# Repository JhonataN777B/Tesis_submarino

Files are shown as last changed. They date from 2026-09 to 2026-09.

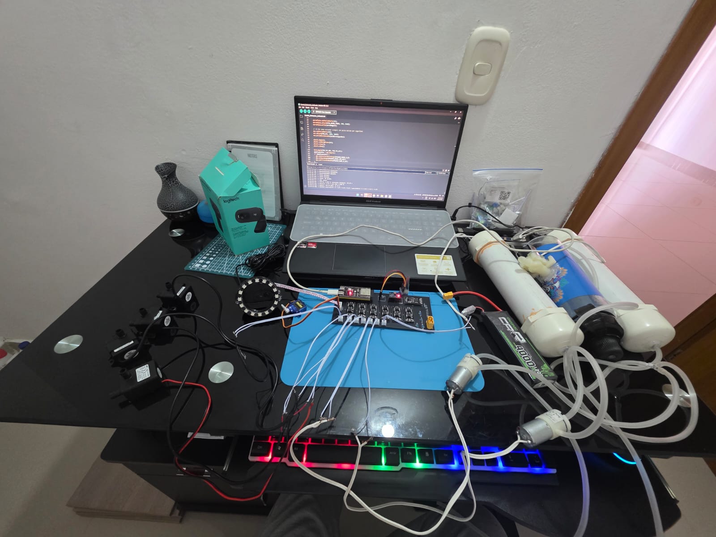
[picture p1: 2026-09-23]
docs/evidencia/pcb/Montaje.jpeg

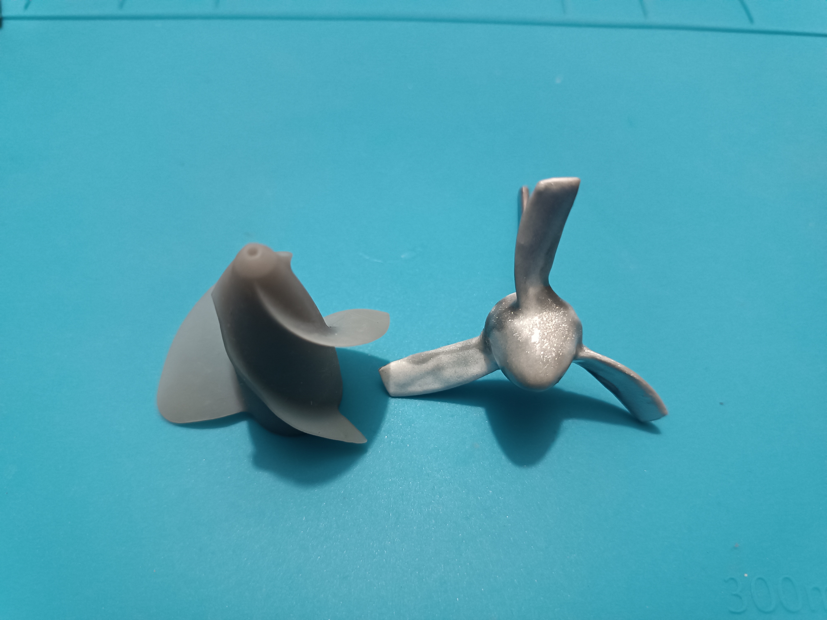
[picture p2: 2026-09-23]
docs/evidencia/primera_version_submarino/231.jpg

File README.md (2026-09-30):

# ROV / Submarine thesis

Repository for the low-cost remotely operated vehicle (ROV): ESP32-S3 firmware, surface-control interface, hardware exports, telemetry examples, and validation evidence.

## Repository layout

- firmware/integrated: current ESP32-S3 integrated firmware.
- firmware/tests: independent Arduino sketches for sensor and actuator checks.
- interface/solo_control.py: current joystick, serial, camera HUD, telemetry, logging, and recording application.
- interface/prueba_control_mando.py: independent PG-9076/Pygame axis and button diagnostic.
- hardware: PCB files and STL models used for the printed assembly.
- data: a lightweight, illustrative telemetry sample. Runtime logs are not committed.
- docs/evidencia: PCB, design, and selected operational evidence videos.

## Current integration

The firmware streams telemetry at 10 Hz over 115200-baud serial and accepts text commands on the same port. It reads the ACS712, battery divider, MS5837 pressure sensor, and BNO055/SEN0374 orientation sensor when available. Missing sensor values are printed as --. The Python interface accepts current 24-field rows and legacy 20-field rows.

The BNO055 is configured for NDOF fusion. The Python HUD shows heading (yaw), pitch, and roll, and logs telemetry; the current software does not implement automatic attitude or depth stabilization.

The Python controller defaults to COM3 and camera index 1. Adjust those settings in interface/solo_control.py for the computer in use. Close Arduino Serial Monitor before starting the Python app because both need the same COM port.

## Setup

1. Open firmware/integrated/Control_Submarino_Unificado.ino in Arduino IDE.
2. Install ESP32Servo, Adafruit NeoPixel, a compatible MS5837 library, and DFRobot_BNO055.
3. Install Python dependencies from interface/requirements.txt.
4. Set the correct serial port and camera index in interface/solo_control.py.
5. Review docs/protocolo_serial.md and docs/pruebas.md before an integrated test.

Keep the vehicle restrained and verify stop/neutral before testing propulsion.

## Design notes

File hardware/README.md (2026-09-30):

# Hardware

## PCB

- pcb/BOM_Tesis_2026-08-29.csv: lista de materiales exportada del diseno.
- pcb/Gerber_Tesis_PCB_Tesis_2026-08-29.zip: paquete Gerber para fabricacion.
- pin_map.md: asignacion de GPIO del ESP32-S3.

## Modelos STL usados para impresion

- Pieza_frontal.stl y Pieza_trasera.stl: piezas frontal y trasera.
- soporte_garra.stl: soporte de la pinza.
- soporte_motor.stl: soporte del motor.
- soporte_1.stl, soporte_2.stl y soporte_3.stl: soportes complementarios.

Estos son exportes STL para fabricacion. Los archivos CAD editables, el proyecto de Inventor/Blender y simulaciones se conservan en las carpetas de trabajo originales.

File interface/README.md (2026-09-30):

# Control de superficie

## Aplicacion integrada

solo_control.py es la aplicacion activa para el mando Bluetooth, ESP32, HUD de camara, visualizacion de telemetria, graficas, logs y grabacion del HUD.

Instale las dependencias con:

    pip install -r requirements.txt

Ajuste PUERTO_COM y CAMARA dentro de solo_control.py. El programa usa 115200 baudios y comparte el puerto serie con los comandos del ESP32. Cierre el Monitor Serial de Arduino antes de ejecutar Python.

El firmware emite telemetria a 10 Hz. El panel muestra la lectura de sensores; los valores ausentes aparecen como --. Los logs CSV de cada sesion y su espejo de respaldo se escriben en interface/Logs_Submarino cuando el programa se ejecuta desde esta carpeta. Las grabaciones iniciadas desde el mando se guardan en Grabaciones_HUD.

## Mando PG-9076

Indices confirmados con Pygame:

| Control | Funcion |
| --- | --- |
| Palanca izquierda vertical | Control del ESC (1000-2000 us; neutro 1500 us) |
| Palanca derecha horizontal | Orden de giro derecha/izquierda |
| Palanca derecha vertical | Orden de roll derecha/izquierda |
| A, boton 0 | Solicita reinicio seguro del ESP32 |
| B, boton 1 | Alterna abrir/cerrar pinza |
| X, boton 3 | Alterna bomba de aire 1 |
| Y, boton 4 | Alterna bomba de aire 2 |
| Boton 7 | Alterna electrovalvula |
| Boton 10 | Inicia/detiene grabacion del HUD |
| Start, boton 11 | Alterna LISTO/OPERANDO |

Start deja el vehiculo en LISTO al detener y exige centrar las palancas antes de habilitar movimiento al volver a OPERANDO. El boton A solicita el reinicio seguro del ESP32.

La tecla G cambia entre HUD y graficas; R alterna la grabacion y Q cierra la ventana. El boton 10 del mando tambien alterna la grabacion.

## Diagnostico independiente del mando

prueba_control_mando.py muestra ejes, botones y cruceta sin controlar el ROV. Uselo para comprobar un mando o volver a confirmar su mapeo antes de operar.

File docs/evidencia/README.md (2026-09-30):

# Evidencia del proyecto

## Primera version construida

Las fotos de primera_version_submarino documentan la primera unidad construida y no representan por si solas la configuracion de version 2.

## Version 2 y PCB

- version_2_submarino contiene renders del diseno de la segunda version.
- pcb contiene DATOS.jpeg y Montaje.jpeg de la PCB.

## Pruebas de operacion (30-09-2026)

- [Prueba de funcionamiento del aro LED](operacion/aro_led_operativo_2026-09-30.mp4).
- [Telemetria en tiempo real](operacion/telemetria_tiempo_real_2026-09-30.mp4).

## FEA y archivos tecnicos

Las pruebas FEA e imagenes se conservan en el documento compartido por el usuario: [Abrir documento FEA](https://1drv.ms/w/c/5849b21efb36e423/IQC6wTvbUKNUTo-QrPtmvVhxAYxSXWxDTwB7AuLJp3VFQAA?e=XMopzp).

Los modelos STL de fabricacion estan en ../../hardware. Los modelos CAD editables, Blender y simulaciones permanecen en las carpetas de trabajo del proyecto.

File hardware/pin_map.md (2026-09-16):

# Mapa de pines — ESP32-S3

Fuente: `firmware/integrated/Control_Submarino_Unificado.ino`. Validar en el PCB antes de conectar cargas.

| GPIO | Señal | Función |
| --- | --- | --- |
| 1 | ACS712 | Corriente (ADC) |
| 2 | SERVO_PINZA | Servo de pinza |
| 4 | BOMBA_AI | Bomba de agua, adelante izquierda |
| 5 | BOMBA_AD | Bomba de agua, adelante derecha |
| 6 | AIRE_1 | Bomba de aire 1 |
| 7 | AIRE_2 | Bomba de aire 2 |
| 8 | I2C_SDA | Bus I²C: MPU6050 y MS5837 |
| 9 | I2C_SCL | Bus I²C: MPU6050 y MS5837 |
| 10 | BATERIA | Voltaje de batería (ADC) |
| 11 | BOMBA_BI | Bomba de agua, atrás izquierda |
| 12 | BOMBA_BD | Bomba de agua, atrás derecha |
| 13 | ELECTROVALVULA | Electroválvula de lastre |
| 15 | ESC | Señal PWM del propulsor |
| 21 | NEOPIXEL | Aro LED (16 píxeles configurados) |

Los GPIO 1 y 10 usan ADC de 12 bits. El firmware presupone divisor de batería de 30 kΩ/10 kΩ y divisor 10 kΩ/10 kΩ para la salida del ACS712.

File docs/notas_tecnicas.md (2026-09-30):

# Notas tecnicas

## Firmware ESP32-S3

- Librerias externas: ESP32Servo, Adafruit NeoPixel, MS5837 compatible con MS5837.h y DFRobot_BNO055. Wire, math y Preferences pertenecen al core/SDK.
- BNO055/SEN0374 por I2C: SDA GPIO 8, SCL GPIO 9; direcciones probadas 0x28 y 0x29. Se selecciona modo NDOF y se leen aceleracion, giroscopio, magnetometro y Euler (head/roll/pitch).
- El rumbo se normaliza a 0-360 grados; la calibracion/perturbacion magnetica afecta su confiabilidad.
- El MS5837, ACS712 y divisor de bateria alimentan la telemetria. El factor de bateria se calibra con calibrar_bateria <V_multimetro> y se conserva en Preferences.
- La telemetria integrada sale cada 100 ms (10 Hz). Los valores de sensores ausentes se escriben como --.
- El ESC reversible usa 1000-2000 us y neutro 1500 us. GPIO15 controla la señal a traves del NPN previsto por el montaje.
- El aro NeoPixel usa GPIO21 y 16 pixeles; el umbral configurado de bateria baja es 10.5 V.

## Interfaz y archivos de sesion

- La aplicacion actual es interface/solo_control.py; interface/prueba_control_mando.py sirve solo para diagnosticar el PG-9076.
- El HUD requiere OpenCV, NumPy, PySerial y Pygame. El indice de camara y COM se ajustan en el script.
- La interfaz guarda CSV con coma entre columnas y punto decimal, y mantiene una copia en Respaldo. Los CSV y videos de usuario en carpetas de ejecucion se excluyen del repositorio.
- Los videos seleccionados de prueba se conservan bajo docs/evidencia/operacion.

## Activos de hardware

- hardware contiene el mapa de pines, BOM/Gerbers y STL elegidos para imprimir.
- Los originales/editables de Inventor, Blender y simulacion permanecen en las carpetas de trabajo originales.

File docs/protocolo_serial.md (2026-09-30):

# Protocolo serial

## Parametros

- Velocidad: 115200 baudios.
- Fin de linea de comandos: LF (\n).
- El mismo puerto se usa para comandos y telemetria; cierre el Monitor Serial antes de conectar la interfaz Python.

## Telemetria del firmware integrado

El firmware transmite una fila cada 100 ms (10 Hz), con campos separados por espacios. Imprime una fila de titulos cada 20 muestras. Los sensores no disponibles se representan con --.

Orden de las 24 columnas actuales:

1. ACS712 ADC (V)
2. Corriente filtrada (A)
3. Potencia electrica (W)
4. Bateria (V)
5. Pulso ESC (us)
6. Presion (mbar)
7. Temperatura (C)
8. Profundidad (m)
9-11. Aceleracion X/Y/Z (g)
12-14. Giroscopio X/Y/Z (deg/s)
15-17. Magnetometro X/Y/Z (uT)
18. Roll (deg)
19. Pitch (deg)
20. Yaw/heading (deg)
21-24. Calibracion BNO055: sistema, giroscopio, acelerometro y magnetometro (0-3)

La interfaz acepta tanto las 24 columnas actuales como las 20 columnas de versiones anteriores; en el formato antiguo, los cuatro estados de calibracion quedan vacios. Los datos recibidos se presentan en el HUD y se guardan como CSV con una columna por campo, coma como separador y punto decimal. Cada sesion tiene una copia espejo en Respaldo.

## Comandos

- Estado y seguridad: ayuda, estado, iniciar, stop.
- Reinicio: reiniciar (tambien acepta reinicio o reset); detiene las salidas y reinicia el ESP32.
- ESC reversible: esc 1000..2000; neutro 1500 us; esc_off vuelve a neutro.
- Bombas de movimiento: adelante/a, derecha/d, izquierda/i, roll_derecha/rd, roll_izquierda/ri, agua_off.
- Aire: aire_on, aire_off, aire1_on, aire1_off, aire2_on, aire2_off.
- Electrovalvula: valvula_on, valvula_off.
- Pinza: abrir, cerrar, servo 0..180.
- Calibracion de bateria: calibrar_bateria <voltaje del multimetro>; guarda el factor en memoria no volatil del ESP32.
- Presion: calibrar_superficie con el sensor fuera del agua.
- BNO055: calibrar_imu y calibrar_brujula muestran estado de calibracion; para mejorar el magnetometro, mueva el vehiculo lentamente en forma de ocho lejos de metal y corrientes del motor.

## Interfaz de superficie

interface/solo_control.py lee continuamente el flujo serial, envia comandos del mando y registra una sesion. El archivo interface/prueba_control_mando.py solo diagnostica los indices del mando; no envia comandos al submarino.

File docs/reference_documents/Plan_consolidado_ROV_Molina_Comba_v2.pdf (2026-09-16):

Plan consolidado de trabajo de grado - ROV

Molina - Comba | Versión 2 | 12 de agosto de 2026

# PLAN CONSOLIDADO DE TRABAJO DE GRADO

## Diseño y construcción de un ROV teleoperado de bajo costo para recuperación y visualización en aguas someras

Estudiantes: Kevin Sebastián Comba Carranza y Jhonatan Alberto Molina Amaya Asesor: David Reinerio Yanguas Rojas Ingeniería Mecatrónica - Uniagustiniana
Semana actual: 2 de 12 | Cierre técnico planeado: semana 10 | Semanas 11-12: holgura

Propósito de esta versión
Actualizar el plan de trabajo a partir del estado real del documento, fortalecer el marco metodológico, separar claramente el experimento científico de las pruebas de aceptación de ingeniería y dejar un cronograma ejecutable por dos estudiantes con documentación paralela desde la semana 2.

Versión 2 - 12 de agosto de 2026

## 1. Diagnóstico del documento actual

El documento ya tiene una estructura útil y recoge el núcleo técnico del proyecto, pero todavía conserva decisiones de versiones anteriores y mezcla variables de investigación con indicadores generales de desempeño. La prioridad de esta semana no es aumentar páginas, sino cerrar coherencia entre el producto que realmente se construirá, la pregunta de investigación, los objetivos y el experimento.

Aspecto | Corrección prioritaria
Profundidad | El Abstract todavía declara operación hasta 2 m, mientras el escenario repetible de pruebas será la fuente de la universidad, de aproximadamente 1 m. Debe declararse como escenario principal de validación y dejar profundidades mayores solo como pruebas adicionales, si son viables.
Control | La introducción menciona control automático y la metodología todavía usa “algoritmo PID” como variable controlada. El compromiso oficial será teleoperación; cualquier controlador automático o filtro de Kalman debe quedar como extensión opcional.
Propulsión y profundidad | La arquitectura actual debe reflejar un motor sumergible con hélice principal para X, bombas para maniobra en Y y yaw, y un sistema neumático de flotabilidad/lastre para Z. Deben eliminarse referencias obsoletas a jeringas cuando ya no correspondan.
Energía | La metodología actual usa consumo de corriente como variable dependiente. La comparación debe migrar a energía por unidad de distancia como variable principal, midiendo simultáneamente tensión y corriente.
Muestra | El documento fija 30 repeticiones por hélice y afirma que esto garantiza potencia estadística, pero no presenta cálculo de potencia, efecto mínimo detectable ni variabilidad esperada. Esta afirmación debe reemplazarse por un cálculo explícito y un piloto.
Recuperación | La pinza sigue siendo crítica para el propósito del proyecto, pero no aparece suficientemente priorizada en el cronograma. Debe existir un prototipo de sujeción funcional antes de la integración completa.
APA | La plantilla contiene ejemplos y vacíos que no deben copiarse literalmente: faltan citas dentro de varias secciones, hay notas de tablas/figuras no conformes y existen referencias sin correspondencia clara con citas en el texto.

Decisión de alcance
El trabajo se presenta como diseño y construcción de un único ROV. La iteración anterior se documentará como antecedente técnico y evidencia del proceso iterativo de diseño, pero no se venderá como un proyecto de rediseño.

## 2. Planteamiento consolidado

### 2.1 Título recomendado

Diseño y construcción de un ROV teleoperado de bajo costo para visualización y recuperación de objetos en aguas someras

### 2.2 Núcleo del problema de investigación

El proyecto busca resolver un problema de ingeniería y, simultáneamente, incorporar una pregunta experimental concreta. El problema de ingeniería consiste en integrar en una plataforma académica de bajo costo los subsistemas de estanqueidad, flotabilidad, estabilidad, propulsión, teleoperación, percepción y manipulación necesarios para ejecutar una misión básica de visualización y recuperación en aguas someras. El componente investigativo se concentra en la selección de la hélice principal a partir de evidencia cuantitativa de consumo energético y desempeño funcional.
El documento no debe afirmar todavía que existe una “brecha en la literatura” respecto de las hélices toroidales o que estas son más eficientes. Primero debe sustentarlo con una revisión bibliográfica reciente y específica. La formulación debe ser neutral: se comparan dos configuraciones porque existe una decisión de diseño relevante que puede resolverse experimentalmente.

### 2.3 Pregunta de investigación

Pregunta propuesta
¿Cómo diseñar y construir un ROV teleoperado de bajo costo para visualización y recuperación de objetos en aguas someras, incorporando una selección experimental de la configuración de hélice principal con base en su consumo energético y desempeño funcional?

### 2.4 Hipótesis para el experimento de hélices

- H1: La geometría de la hélice principal produce diferencias medibles en el consumo energético específico del ROV durante el desplazamiento longitudinal bajo condiciones controladas de operación.
- H0: La geometría de la hélice principal no produce diferencias medibles en el consumo energético específico del ROV durante el desplazamiento longitudinal bajo las condiciones evaluadas.
La hipótesis es deliberadamente neutral respecto de qué geometría será superior. Si la hélice toroidal resulta peor, el experimento sigue siendo válido y la decisión de diseño estará sustentada por evidencia.

### 2.5 Objetivo general

Desarrollar un ROV teleoperado de bajo costo para visualización y recuperación de objetos en aguas someras, con capacidad de movimiento en X, Y, Z y yaw y selección experimental de la configuración de hélice principal según su desempeño energético.

### 2.6 Objetivos específicos

1. Diseñar la arquitectura mecánica del ROV considerando requerimientos de estanqueidad, flotabilidad, estabilidad, resistencia estructural, propulsión y manipulación mediante modelado CAD, cálculos de ingeniería y análisis por elementos finitos de los componentes críticos.

2. Implementar la arquitectura electrónica y de teleoperación del ROV integrando alimentación, PCB, actuadores, instrumentación, transmisión de video y un mecanismo de sujeción para recuperación de objetos pequeños.
3. Caracterizar experimentalmente las configuraciones de hélice convencional y toroidal mediante mediciones de consumo energético específico y variables complementarias de velocidad y estabilidad bajo condiciones controladas de operación.
4. Validar el desempeño integrado del ROV mediante pruebas de estanqueidad, movilidad, estabilidad, visualización y recuperación de objetos en aguas someras.

## 3. Arquitectura funcional de referencia

Función | Solución base | Observación
Movimiento X | Motor sumergible + hélice principal intercambiable | Comparación convencional vs. toroidal.
Movimiento Y | Bombas laterales | Validar empuje suficiente y simetría.
Movimiento Z | Sistema neumático de flotabilidad/lastre | Debe modificar volumen desplazado o masa de agua embarcada; no basta con presurizar un volumen rígido cerrado.
Yaw | Bombas laterales | Teleoperado.
Roll / Pitch | Estabilidad pasiva | Diseño de CG/CB y distribución de masa/flotación.
Visión | Cámara frontal + tether | Batería interna: el tether no debe describirse como fuente principal de alimentación si no lo es.
Recuperación | Pinza 1 GDL con servo e imanes | Electroimán como alternativa opcional si supera matriz de selección.
Instrumentación | Presión/profundidad, IMU, temperatura, tensión y corriente | RPM opcional si la instrumentación resulta sencilla.
Control | Teleoperación | Control automático y filtro de Kalman solo como plus.
Energía | LiPo 3S interna | Carga externa sellada; definir protección, fusible y umbrales antes de congelar PCB.

Chequeo rápido del sistema de flotabilidad
A 1 m de profundidad, la presión hidrostática adicional es aproximadamente 9,8 kPa (0,098 bar). Si el volumen útil del tanque/vejiga es 300 mL, el cambio máximo ideal de empuje es aproximadamente 2,94 N, equivalente a unos 0,30 kgf. Antes de fabricar el sistema definitivo deben verificar que este margen sea suficiente para vencer la flotabilidad residual, pérdidas y perturbaciones.

## 4. Metodología revisada

Se recomienda clasificar el trabajo como investigación aplicada y desarrollo tecnológico con enfoque cuantitativo y componente experimental. La metodología debe separar dos cosas que actualmente aparecen mezcladas: (1) el experimento comparativo que responde a la hipótesis de hélices y (2) las pruebas de aceptación que verifican que el ROV cumple los requisitos de ingeniería.

### 4.1 Fases metodológicas

Fase A - Diseño y especificación: Requerimientos, arquitectura, CAD, cálculos de flotabilidad/CG-CB, diseño de pinza, sistema de profundidad, selección de componentes y FEA de piezas críticas.
Fase B - Construcción e integración: Fabricación, PCB, ensamblaje, sellado, firmware mínimo de teleoperación, sensórica y data logging.
Fase C - Calibración y piloto: Calibración de tensión/corriente, IMU y profundidad; piloto de hélices; verificación del protocolo y estimación inicial de variabilidad.
Fase D - Experimento de hélices: Comparación controlada de dos geometrías usando energía por distancia como respuesta principal.
Fase E - Validación integrada: Estanqueidad, movilidad X/Y/Z/yaw, estabilidad, video y recuperación de objeto.
Fase F - Análisis y documentación: Estadística descriptiva/inferencial según datos, BOM, análisis beneficio-costo, discusión, conclusiones, anexos y evidencias.

### 4.2 Variables del experimento principal de hélices

Estas son las variables que deben aparecer como variables de investigación. La tasa de recuperación, la estanqueidad o la latencia no son variables dependientes de la geometría de hélice salvo que se diseñe explícitamente un experimento para relacionarlas; se manejan mejor como indicadores de validación del sistema.

Tipo | Variable | Operacionalización | Instrumento / unidad
Independiente | Geometría de hélice | Dos niveles: convencional de 3 palas y toroidal. Mantener el mismo motor y, en lo posible, diámetro exterior comparable. | Registro de configuración / CAD
Dependiente primaria | Energía consumida por unidad de distancia | E_d = integral[V(t)·I(t) dt] / d. Resultado en J/m o Wh/m. | Sensores de tensión y corriente + registro temporal + distancia
Dependiente secundaria | Velocidad media | v = d/t para un trayecto estandarizado. | Marcas métricas + video/cronómetro, m/s
Dependiente secundaria | Potencia eléctrica media y pico | P(t)=V(t)·I(t); promedios y máximos por recorrido. | Sensores V/I, W
Dependiente secundaria | Estabilidad de orientación | Media, RMS o desviación de roll y pitch durante el tramo estable. | IMU, grados
Opcional | RPM del eje | Solo si puede medirse sin aumentar sustancialmente complejidad o riesgo de estanqueidad. | Encoder magnético/tacómetro, rpm

### 4.3 Variables controladas del experimento de hélices

- Mismo ROV, motor, controlador, firmware de propulsión y ubicación del propulsor.
- Masa total y distribución de lastre/flotación sin modificaciones entre condiciones.

- Distancia de prueba, profundidad nominal y orientación inicial.
- Comando PWM o consigna de accionamiento previamente definida.
- Rango de tensión/estado de carga permitido al inicio de cada bloque experimental.
- Configuración y tendido del tether, procurando la misma longitud libre y orientación.
- Condiciones del agua y zona de prueba; evitar comparar ensayos con chorros, limpieza o perturbaciones evidentes.
- Diámetro exterior y material de las hélices tan comparables como sea viable; documentar las diferencias geométricas inevitables.
- Tasa de muestreo, calibración y filtrado aplicado a sensores.

### 4.4 Experimento 1 - Comparación energética de hélices

1. Definir dos geometrías imprimibles y documentar sus parámetros CAD y proceso de fabricación.
2. Calibrar medición de tensión y corriente con un instrumento de referencia antes de la campaña.
3. Ejecutar un piloto de 6 pares de recorridos para detectar fallos del protocolo y estimar la variabilidad de la diferencia de energía por metro.
4. Usar bloques pareados: cada bloque debe incluir al menos un recorrido válido con cada hélice bajo condiciones cercanas de batería y agua. Alternar o aleatorizar el orden para reducir sesgos por descarga de batería.
5. Usar un trayecto estandarizado de 1 m cuando la geometría de la fuente lo permita. Registrar V(t), I(t), tiempo, IMU y observaciones de cada corrida.
6. Descartar y repetir únicamente corridas con criterio predefinido: colisión, enganche del tether, intervención externa, pérdida de datos o incumplimiento del protocolo. No descartar datos por “salir mal”.
7. Calcular energía por metro, potencia media/pico, velocidad y métricas de roll/pitch. Comparar primero con gráficos e intervalos; seleccionar prueba inferencial después de revisar distribución y estructura de datos.

### 4.5 Cálculo del volumen experimental - hélices

Como todavía no existe una estimación experimental fiable de la variabilidad, no es metodológicamente correcto afirmar que “30 repeticiones garantizan potencia”. La muestra final debe recalcularse después del piloto. Para planear recursos se puede usar un contraste pareado bilateral con alpha = 0,05 y potencia = 0,80.

Fórmula de planificación
Para una diferencia mínima relevante Δ y una desviación estándar de las diferencias σ_d: n [(z_(1- ≈ α/2) + z_(1-β)) · σ_d / Δ]^2. En términos de tamaño de efecto pareado d_z = Δ/σ_d, el número requerido depende de qué tan grande sea la diferencia que realmente se considera importante.
Supuesto de efecto pareado d_z | Interpretación | Pares requeridos aprox. | Recorridos válidos (2 hélices)
0,50 | Efecto medio | 34 | 68
0,60 | Medio-alto | 24 | 48

Supuesto de efecto pareado d_z | Interpretación | Pares requeridos aprox. | Recorridos válidos (2 hélices)
0,67 | Ejemplo: mejora 10% con SD de diferencias 15% | 20 | 40
0,80 | Efecto alto | 15 | 30
1,00 | Efecto muy alto | 10 | 20
Plan recomendado: realizar 6 pares piloto y recalcular. Como estimación de planificación, 20 pares (40 recorridos) es una meta razonable si se busca detectar una diferencia del orden del 10% con una variabilidad de diferencias cercana al 15%. Si por viabilidad solo se alcanzan 10-12 pares, se deben reportar intervalos de confianza, la potencia limitada y evitar conclusiones fuertes de equivalencia o superioridad.

### 4.6 Experimento 2 / prueba de recuperación

La recuperación de objetos es una prueba de aceptación funcional, no una variable dependiente del experimento de hélices. Debe definirse un objeto patrón, una posición inicial y un criterio binario de éxito antes de iniciar la campaña.
- Objeto patrón sugerido: aproximadamente 5 x 5 x 5 cm y 50-100 g, con material y superficie documentados.
- Éxito: aproximación, agarre, elevación controlada y traslado/recuperación sin pérdida del objeto dentro del tiempo máximo definido.
- Pinza base: 1 GDL con servo impermeabilizado y dedos con asistencia magnética. Evaluar electroimán mediante matriz de selección antes de convertirlo en requisito.
- Registrar éxito/fallo, tiempo de misión, causa del fallo y observaciones de estabilidad.
Volumen experimental para una proporción: si se desea estimar una tasa real cercana al 80% con 95% de confianza, el tamaño aproximado por precisión es n = z²·p(1-p)/e². Esto produce:
Precisión deseada (±e) | n teórico aprox. para p=0,80 | Uso recomendado
±20% | 16 | Demostración preliminar
±15% | 28 | Validación moderada
±10% | 62 | Estimación rigurosa, poco viable en este semestre

Compromiso práctico: mantener como criterio de ingeniería una tasa observada >=80%. Internamente, apuntar a 20 intentos válidos (16 éxitos) y usar como mínimo aceptable 10 intentos solo si el tiempo obliga. Si se ejecutan menos de 28, no presentar el porcentaje observado como una estimación precisa de la tasa poblacional; reportarlo como validación funcional limitada por viabilidad.

### 4.7 Pruebas de aceptación del ROV

Subsistema | Prueba | Compromiso oficial mínimo | Meta interna
Estanqueidad | Inmersión progresiva sin electrónica y luego integrada | 30 min a profundidad de operación sin ingreso de agua que comprometa el sistema | 60 min y repetición después de cada intervención de sellado
Profundidad | Operación en fuente universitaria | Operación funcional hasta ~1 m | Prueba aislada >1 m solo si es segura y aporta información

Subsistema | Prueba | Compromiso oficial mínimo | Meta interna
Movilidad | Comandos X, Y, Z y yaw | Ejecución teleoperada reproducible de los cuatro movimientos | 5 repeticiones por maniobra sin pérdida de control
Estabilidad | Roll y pitch durante operación estabilizada | <=15° en condiciones nominales | Caracterizar distribución y reducir dispersión
Video | Transmisión durante misión | Latencia <=2 s y sin pérdida prolongada | Medir también FPS/caídas si es sencillo
Recuperación | Objeto patrón | >=80% de éxitos en la muestra ejecutada | 20 intentos válidos
Energía | Autonomía y consumo | Registrar autonomía real; no convertir 45 min en condición de aprobación | Apuntar a 30-45 min o más según batería final
Costo | BOM y manufactura | Costo directo documentado | Comparar con referencias comerciales sin incluir horas de desarrollo

## 5. Recomendaciones técnicas accionables

### 5.1 Diseño mecánico e Inventor/FEA

- Cerrar lista de piezas que se conservan/cambian antes de terminar la semana 2; documentar cada decisión con motivo técnico.
- Calcular masa real, volumen desplazado, flotabilidad residual y posición aproximada de CG/CB antes de “balancear a prueba y error”.
- Usar FEA solo en piezas críticas: tapas/carcasa, soportes del propulsor, estructura cargada por la pinza o uniones con concentración de esfuerzos.
- Para cada simulación registrar: carga aplicada, condición de frontera, propiedad del material, fuente de la propiedad, malla, esfuerzo/deformación máxima, factor de seguridad y decisión de diseño derivada.
- En piezas impresas declarar la simplificación isotrópica si se usan propiedades genéricas y reconocer anisotropía/proceso de impresión como limitación.
- No usar FEA como sustituto de pruebas de estanqueidad: resistencia y hermeticidad son problemas distintos.

### 5.2 Sistema de agarre

- Elevar su prioridad: debe existir una prueba de agarre funcional en seco y luego en agua antes de la semana 5.
- Diseñar dedos intercambiables o superficies de contacto simples que permitan ajustar geometría sin rehacer toda la pinza.
- Impermeabilizar el servo con un método reproducible y documentar la profundidad/tiempo de prueba.
- Evaluar tres conceptos: pinza mecánica, pinza + imanes permanentes, pinza + electroimán. Elegir con matriz de criterios: versatilidad, masa, consumo, sellado, complejidad, fuerza de retención y seguridad.
- Si se usa electroimán, no convertirlo en requisito hasta verificar consumo, calentamiento y compatibilidad con el objeto patrón.

### 5.3 Electrónica, PCB y medición

- No congelar drivers de bombas/motor hasta medir o confirmar corriente nominal y de arranque.
- Seleccionar sensor de corriente y método de medida de tensión con rango suficiente; un watímetro puede servir como referencia de banco, pero el data logging de V(t) e I(t) es preferible para integrar energía.
- Calibrar sensores contra instrumentos de referencia antes de la campaña experimental.
- Definir protección de la LiPo 3S: fusible cercano a la batería, monitoreo de bajo voltaje, protección de polaridad y procedimiento de carga fuera del agua. La terminal externa debe quedar sellada durante operación.
- No afirmar “BMS” si el pack/arquitectura final no lo usa; describir exactamente el mecanismo de protección real.
- Encoder de RPM y filtro de Kalman quedan como opcionales: solo implementar si el ROV ya supera los hitos funcionales.

### 5.4 Software, trazabilidad e IA

- Mantener software simple: teleoperación estable, lectura de sensores, registro temporal y manejo seguro de pérdida de comunicación.
- Usar Git/GitHub como mínimo para firmware, interfaz, documentación y versiones de archivos exportados; no gastar semanas en arquitectura de software avanzada.
- Usar ChatGPT, Claude y Codex para depuración, documentación y revisión, pero verificar físicamente cada función crítica y conservar evidencia de pruebas.
- Registrar decisiones sustantivas asistidas por IA cuando cambien diseño, código o metodología. Los estudiantes deben poder explicar y defender el resultado sin depender del texto generado.

## 6. Reparaciones APA y de coherencia documental

La plantilla institucional debe respetarse como estructura, pero no debe asumirse que todos sus ejemplos cumplen APA 7. Antes de la entrega final, los estudiantes deben normalizar manualmente los elementos que la plantilla deja incompletos o incorrectos.

Elemento | Problema actual / riesgo | Acción requerida
Citas en el texto | Introducción, problema y marco teórico contienen afirmaciones técnicas sin citas visibles suficientes. | Cada afirmación derivada de literatura debe tener cita autor-año; verificar correspondencia 1:1 con Referencias.
Brecha y novedad | Se afirma una brecha local/literaria sin evidencia específica. | Sustentar con estado del arte reciente o reformular como necesidad de diseño/decisión experimental.
Profundidad | Abstract conserva <=2 m. | Cambiar a aguas someras / escenario principal ~1 m; mayores profundidades solo como extensión.
Control | Se menciona control automático/PID como parte central. | Alinear todo el documento con teleoperación; PID/Kalman en trabajos futuros o extensión opcional.
Tether | Definición dice que transmite alimentación. | Corregir si la batería final queda interna: declarar las funciones reales del tether.

Elemento | Problema actual / riesgo | Acción requerida
BMS y batería | Marco conceptual/legal puede no coincidir con arquitectura final. | Nombrar únicamente protecciones realmente implementadas y citar datasheets/estándares correctos.
Tablas y figuras | Plantilla muestra “Nota: ... Fuente: ... autoridad propia”. | APA 7 usa número, título y, cuando aplica, “Nota.”; no añadir “Fuente: elaboración propia” de forma automática. Para material adaptado/reproducido, dar atribución completa y referencia.
Referencias | Faltan DOI/URL en varias entradas y puede haber fuentes listadas no citadas. | Aplicar sangría francesa, orden alfabético, títulos en sentence case, revista/volumen en cursiva y DOI como URL cuando exista.
Normas técnicas | Se usa lenguaje de “cumple con” e IP68. | No afirmar certificación o cumplimiento formal si solo se tomó la norma como referencia de diseño/prueba. Reportar condición real de ensayo.
Unidades y símbolos | Hay expresiones tipo $\le 2 m$ y formatos inconsistentes. | Eliminar sintaxis LaTeX visible; usar SI consistente: 1 m, 2 s, 5 x 5 x 5 cm, espacio entre número y unidad.
Resumen/Abstract | Encabezados y palabras clave son inconsistentes. | Unificar título, versión española/inglesa y palabras clave; revisar traducción técnica después de cerrar objetivos/metodología.
Plantilla residual | Persisten textos “Título 1”, “Ejemplo de tabla”, etc. | Eliminar todo contenido demostrativo antes de la entrega y actualizar TOC/listas automáticas.

Regla práctica APA
La plantilla institucional define la estructura del trabajo; APA 7 debe gobernar citación, referencias, tablas, figuras y estilo académico salvo que exista una instrucción institucional explícita en contrario. No copiar literalmente los ejemplos de la plantilla sin verificarlos.

Cronograma consolidado - semanas 2 a 12

Molina - Comba | Cierre técnico semana 10

## 7. Cronograma consolidado para dos estudiantes

El proyecto debe operar con dos frentes técnicos paralelos y una tercera corriente transversal de documentación. Los roles son sugeridos y pueden intercambiarse según fortalezas; ambos estudiantes siguen siendo responsables del trabajo completo y deben revisar el frente del otro.

Distribución sugerida
Frente A: mecánica, CAD/FEA, flotabilidad, propulsión, pinza y fabricación. Frente B: PCB, alimentación, sensores, firmware, teleoperación y data logging. Trabajo común semanal: integración, experimentos, literatura, redacción, figuras/tablas, bitácora y revisión cruzada.
Semana | Frente A -mecánica/experimento | Frente B -electrónica/software | Trabajo conjunto y documentación | Hito de salida | Plan B / decisión
2 (actual) | Cerrar arquitectura; CAD; cálculo CG/CB; sistema neumático; pinza; concepto de 2 hélices. | Esquemático PCB; drivers; protección LiPo; selección V/I; estructura mínima de firmware. | Reescribir problema, objetivos y metodología; revisar 10-15 fuentes recientes; protocolo experimental borrador. | Arquitectura + variables + protocolo congelados. | No comprar/fabricar elementos críticos sin requerimiento cerrado.
3 | FEA de piezas críticas; fabricar/reimprimir soportes, pinza, tanque/vejiga y hélices piloto. | Cerrar PCB y ordenar/fabricar; pruebas de motor, bombas, servo y sensórica en banco. | Actualizar marco teórico y tabla de requerimientos; registrar cálculos y BOM. | Subsistemas físicos en prueba. | Si flotabilidad variable no funciona, cambiar concepto antes de integrar.
4 | Montaje mecánico; primer agarre en seco/agua; prueba progresiva de estanqueidad del casco. | Soldar PCB; integrar sensores; data logging V/I/IMU/profundidad; cámara/tether. | Documentar calibraciones, FEA y pruebas fallidas; corregir APA. | PCB + casco + pinza funcionales por separado. | No introducir electrónica completa en agua sin superar prueba de casco.
5 | Integración del sistema de flotabilidad, propulsor, bombas y pinza; balance CG/CB. | Integración de PCB, batería, cámara y firmware de teleoperación. | Actualizar diagramas, planos y metodología real; preparar protocolo de aceptación. | Prototipo integrado. | Eliminar funciones opcionales si retrasan integración.
6 | Pruebas de movilidad y estabilidad en poca profundidad; correcciones mecánicas. | Corrección de firmware, seguridad de batería y pérdida de comunicación. | Primera versión completa de capítulos 1-5; tabla de resultados preliminares. | ROV funcional preliminar / primer corte. | Si no hay misión básica, congelar extras y dedicar semana 7 a recuperación.
7 | Afinar Z, roll/pitch y pinza; 10+ intentos de recuperación preliminar. | Calibrar sensores; cerrar pipeline de datos; revisar sincronización temporal. | Cerrar protocolo de hélices y criterios de descarte; preparar hojas de datos. | Misión completa preliminar. | Control automático/Kalman siguen prohibidos si hay fallos básicos.

Cronograma consolidado - semanas 2 a 12

Molina - Comba | Cierre técnico semana 10
Semana | Frente A -mecánica/experimento | Frente B -electrónica/software | Trabajo conjunto y documentación | Hito de salida | Plan B / decisión
8 | Fabricar geometrías definitivas y ejecutar piloto + campaña inicial de hélices. | Monitorear V/I, IMU y profundidad; validar integridad de logs. | Analizar piloto, recalcular muestra y actualizar metodología con n requerido/real. | Dataset experimental usable. | Si no se llega al n teórico, conservar rigor en reporte y reducir alcance inferencial.
9 | Completar campaña de hélices y validación de recuperación/movilidad. | Asegurar datos completos, respaldos y video; correcciones menores. | Estadística, tablas, figuras, discusión, BOM y beneficio-costo. | Prototipo validado + resultados principales. | No hacer cambios de diseño mayores salvo seguridad.
10 | Congelar diseño; planos y evidencias finales. | Congelar firmware/PCB; entregar versiones y manual mínimo. | Cerrar documento, referencias APA, anexos y presentación; revisión cruzada completa. | CIERRE TÉCNICO Y DOCUMENTAL. | Todo cambio posterior debe ser corrección, no nueva funcionalidad.
11 (holgura) | Correcciones puntuales si aparecen fallos de validación. | Correcciones puntuales y respaldo final. | Lectura del asesor/jurado interno; corrección de coherencia y APA. | Versión de radicación. | Usar solo para riesgo real, no para tareas planeadas.
12 (holgura) | Demostración y preparación de respaldo físico. | Preparación de demo y contingencias. | Sustentación, respuestas, repositorio y entrega institucional. | Margen final. | No depender de esta semana para terminar el prototipo.

Plan consolidado - acciones inmediatas

Molina - Comba | Semana 2 de 12

## 8. Lista de recomendaciones accionables

Antes de terminar la semana 2
- ☐ Congelar arquitectura funcional X/Y/Z/yaw y eliminar del documento las versiones obsoletas.
- ☐ Definir el principio físico exacto del sistema neumático de flotabilidad y calcular volumen útil requerido.
- ☐ Pesar prototipo/componentes y actualizar cálculo de empuje, volumen desplazado, CG/CB y margen de lastre.
- ☐ Definir objeto patrón y versión 1 de la pinza; comparar imanes permanentes vs. electroimán mediante matriz simple.
- ☐ Definir dos conceptos de hélice con dimensiones comparables y registrar hipótesis geométricas.
- ☐ Medir/confirmar corriente del motor y bombas antes de elegir drivers y sensores de corriente.
- ☐ Cerrar arquitectura de protección y carga de LiPo 3S; prohibir carga con el ROV sumergido.
- ☐ Reescribir metodología separando variables del experimento y criterios de aceptación.
- ☐ Definir piloto de 6 pares de hélices y hoja de registro experimental.
- ☐ Asignar responsable primario de cada frente y una revisión cruzada semanal de 20-30 min.
- ☐ Crear/ordenar repositorio con carpetas mínimas: /mecanica, /electronica, /firmware, /datos, /documentacion, /evidencias.
- ☐ Revisar y corregir las citas APA de las secciones ya escritas; no esperar a semana 10.
Cada semana
- ☐ Actualizar el documento con decisiones ya tomadas, no con promesas de lo que “se hará”.
- ☐ Registrar una tabla breve de pruebas: fecha, configuración, resultado, fallo, acción correctiva y enlace a evidencia.
- ☐ Actualizar BOM y costos cada vez que se cambia un componente.
- ☐ Guardar al menos una figura/foto/diagrama útil por frente para evitar reconstruir la memoria técnica al final.
- ☐ Revisar que objetivos, metodología y resultados sigan alineados; si cambia el diseño, actualizar el texto ese mismo día.
- ☐ No dedicar tiempo a Kalman, control automático o RPM mientras haya problemas de sellado, flotabilidad, pinza o teleoperación.

## 9. Riesgos y reglas de decisión

Riesgo | Señal de alerta | Decisión inmediata | Fecha límite
Estanqueidad | Cualquier ingreso de agua o condensación que alcance electrónica | Volver a prueba de casco vacío; no seguir integrando | Semana 4
Flotabilidad Z | Tanque/vejiga no genera cambio suficiente o es demasiado lento | Cambiar volumen/arquitectura antes de semana 5 | Semana 3
Pinza | No sostiene el objeto patrón en agua | Simplificar geometría; cambiar superficie/imán/servo | Semana 5
PCB | Corrientes superan drivers o hay caída de tensión | Redimensionar potencia antes de fabricar versión definitiva | Semana 3-4

Plan consolidado - acciones inmediatas

Molina - Comba | Semana 2 de 12
Hélices | No hay diferencias medibles o los datos tienen gran dispersión | Mantener resultado neutral; reportar incertidumbre; no forzar superioridad | Semana 8
Carga de trabajo | Documento se atrasa >1 semana | Asignar 2-3 h fijas/semana de documentación por estudiante | Desde semana 2
Opcionales | Funciones extra consumen tiempo de integración | Congelar extras hasta superar misión básica | Semana 6

## 10. Matriz mínima de coherencia

Objetivo | Método principal | Evidencia esperada | Capítulo / resultado
1. Diseñar | CAD + cálculos + selección conceptual + FEA | Planos, cálculos CG/CB, factores de seguridad, matriz de selección | Diseño mecánico y arquitectura
2. Implementar | PCB + integración + firmware + pinza + sensórica | Esquemáticos, PCB, BOM, pruebas unitarias, código y fotos | Implementación mecatrónica
3. Caracterizar | Experimento comparativo por bloques | Dataset V/I/IMU/tiempo, energía por metro, análisis estadístico | Comparación de hélices
4. Validar | Pruebas de aceptación de misión | Estanqueidad, X/Y/Z/yaw, roll/pitch, video, recuperación | Validación integrada

Criterio de éxito del plan
Al finalizar la semana 10 debe existir un ROV funcional y un documento prácticamente cerrados. Las semanas 11 y 12 se reservan para incertidumbre real, correcciones y sustentación; no deben convertirse en semanas normales de construcción.

Base documental revisada
- Formato APA 7th UniAri 1.docx - estado actual del documento de trabajo de grado.
- Cronograma.pdf - propuesta original de 10 semanas.
- Rúbrica de calificación de anteproyecto 2026-1 - observaciones de Wilson Serrano.
- Metodología.pdf y Formato de anteproyecto - versiones previas de variables, hipótesis y protocolos.
- Guía para elaborar el anteproyecto de Trabajo de Grado en Ingeniería Mecatrónica - criterios metodológicos y de referencias.

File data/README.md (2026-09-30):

# Datos

telemetria_ejemplo.csv es una muestra ilustrativa (no resultados experimentales) con el esquema actual de 27 columnas: tres metadatos de sesion y 24 campos de telemetria.

Los CSV completos se generan durante cada ejecucion de interface/solo_control.py en interface/Logs_Submarino y tienen una copia espejo en Respaldo. Los logs crudos de sesiones y las grabaciones de HUD no se versionan; solo se conservan en el repositorio las evidencias seleccionadas bajo docs/evidencia/operacion.

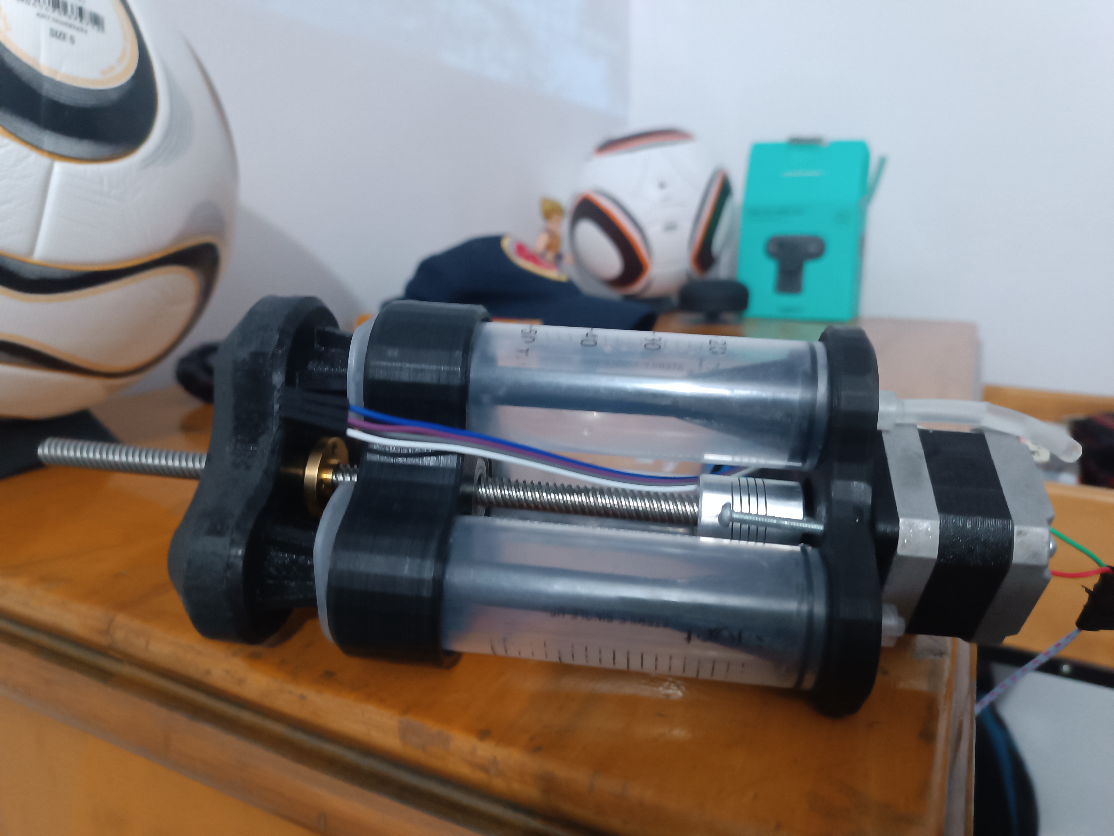
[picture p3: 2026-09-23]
docs/evidencia/primera_version_submarino/a81fc852-9205-48a4-8106-8045b56c1df6-1_all_111.jpg

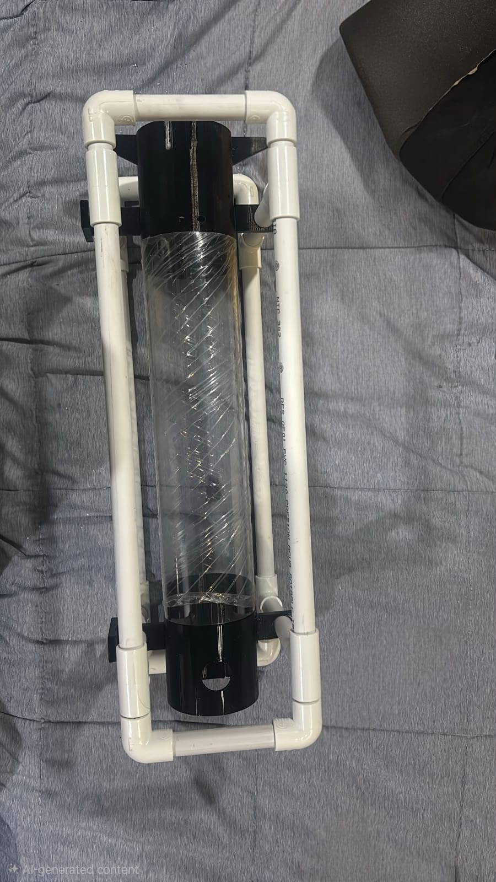
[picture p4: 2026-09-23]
docs/evidencia/version_2_submarino/WhatsApp Image 2026-09-23 at 12.59.52 PM.jpeg

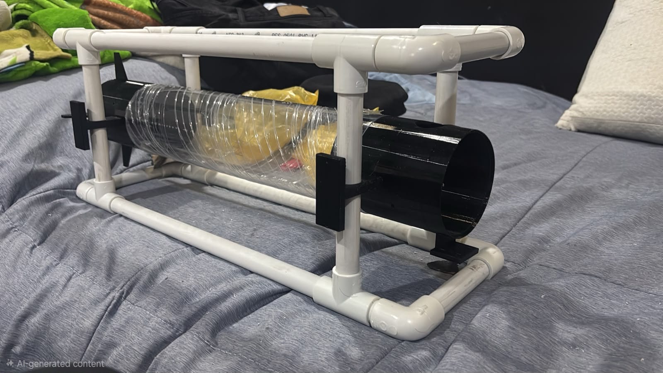
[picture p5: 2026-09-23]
docs/evidencia/version_2_submarino/WhatsApp Image 2026-09-23 at 12.59.51 PM.jpeg

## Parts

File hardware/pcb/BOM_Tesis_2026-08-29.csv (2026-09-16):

ID | Name | Designator | Footprint | Quantity | Manufacturer Part | Manufacturer | Supplier | Supplier Part | Price
1 | 30k | R3 | R_AXIAL-0.4 | 1
2 | 10k | R4,R1,R2 | R_AXIAL-0.4 | 3
3 | LR7843 Modulo mosfet | U2,U3,U4,U5,U6,U7,U8 | MODULO MOSFET LR7843 | 7
4 | HX 2.54MM-4P ZZ-MS | AROLED | CONN-TH_4P-P2.50_HX-2.54MM-4P-ZZ-MS | 1 | HX 2.54mm-4P ZZ-MS | hanxia(韩下) | LCSC | C7543457 | 0.018
5 | HX 2.54MM-2P ZZ-MS | B1,B2,B3,B4,BA1,BA2,V | CONN-TH_2P-P2.50_HX-2.54MM-2P-ZZ-MS | 7 | HX 2.54mm-2P ZZ-MS | hanxia(韩下) | LCSC | C7543455 | 0.01
6 | XT60 | FUENTE | CONN-TH_XT60 | 1 | XT60-M. | AMASS(艾迈斯) | LCSC | C98733 | 0.383
7 | MPU6050 | P1 | MPU6050 | 1
8 | Header-Male-2.54_1x3 | SENSOR(I),SERVO | HDR-TH_3P-P2.54-V-M-1 | 2 | 2.54-1*3P针 | BOOMELE(博穆精密) | LCSC | C49257 | 0.028
9 | ESP32-S3-DEVKITC-1 | U1 | ESP32-S3-DEVKITC-1 | 1 |  | Espressif | Espressif | ESP32-S3-DevKitC-1
10 | MS5837 | U10 | MS5837 | 1

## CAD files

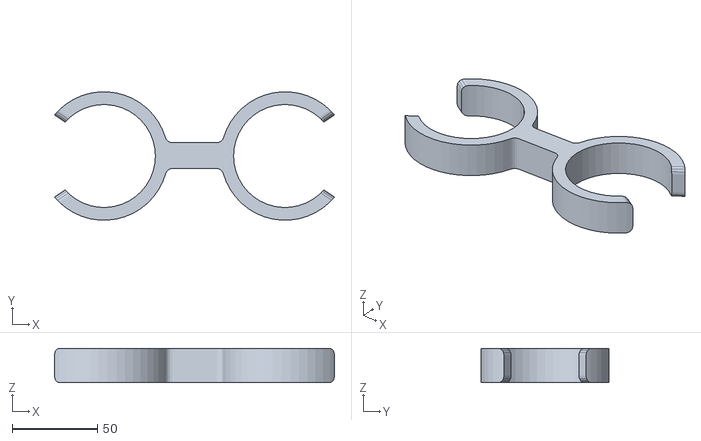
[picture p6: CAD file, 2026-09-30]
hardware/soporte_1.stl
164.4 x 75.3 x 20.0

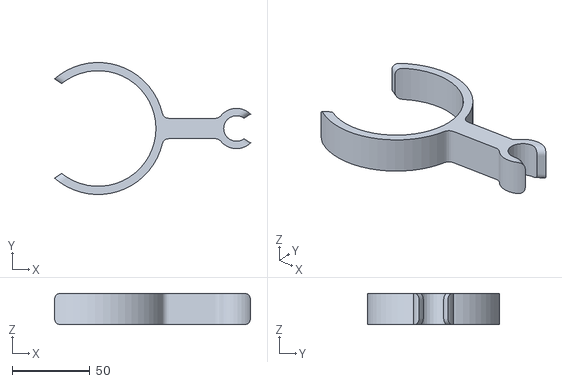
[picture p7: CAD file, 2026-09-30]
hardware/soporte_3.stl
126.1 x 84.9 x 20.0

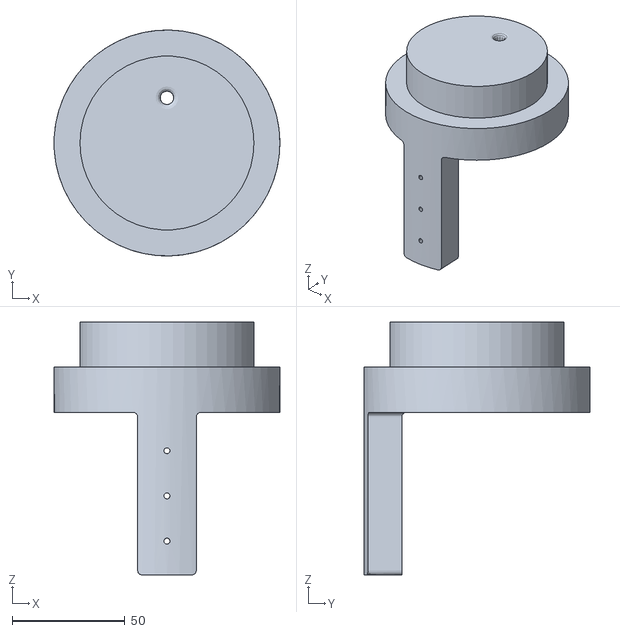
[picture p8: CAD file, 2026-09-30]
hardware/soporte_motor.stl
100.0 x 100.0 x 112.0

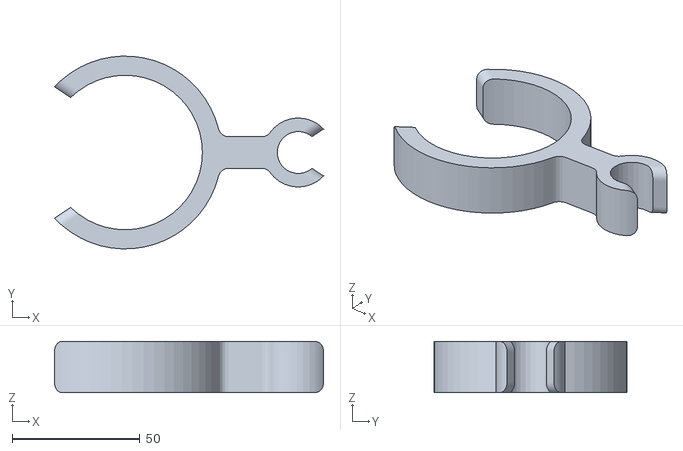
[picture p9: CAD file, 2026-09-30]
hardware/soporte_2.stl
105.2 x 75.4 x 20.0

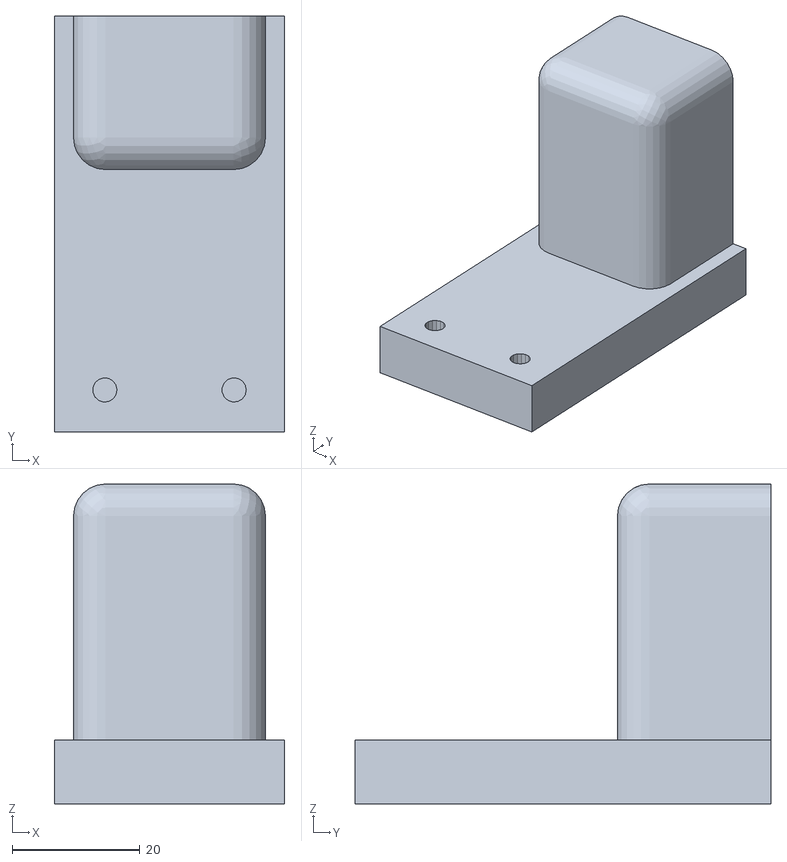
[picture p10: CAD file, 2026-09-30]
hardware/soporte_garra.stl
36.0 x 65.0 x 50.0

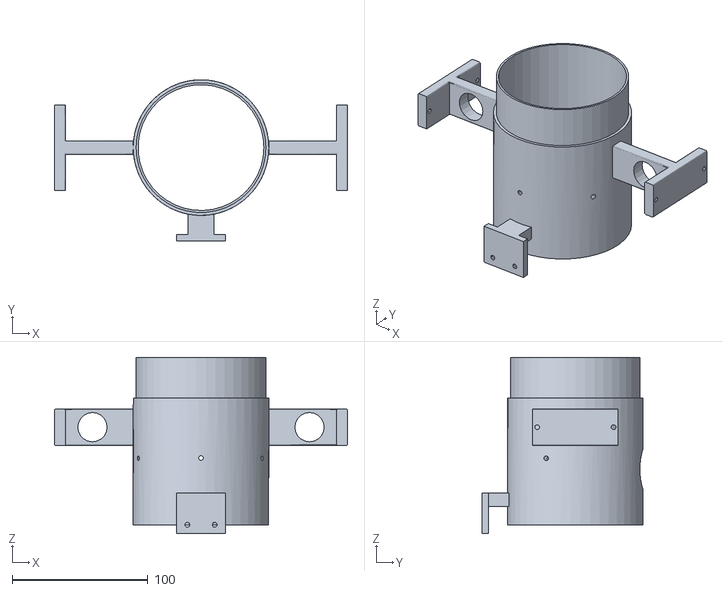
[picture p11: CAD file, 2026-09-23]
hardware/Pieza_frontal.stl
216.0 x 119.0 x 130.0

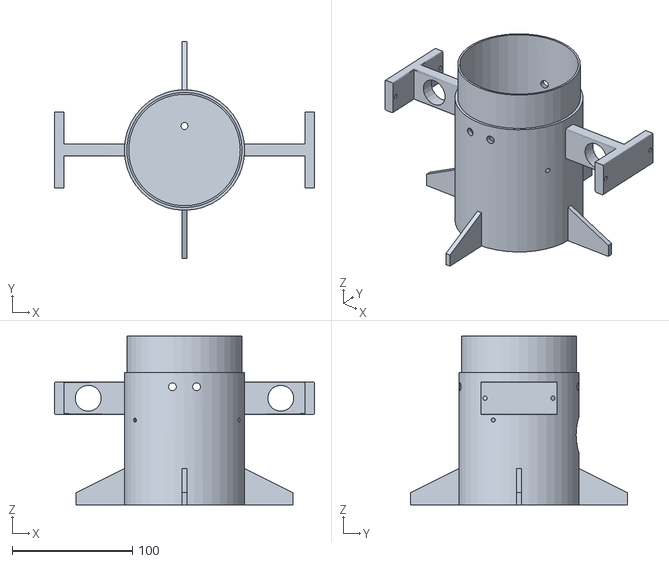
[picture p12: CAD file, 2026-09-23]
hardware/Pieza_trasera.stl
216.0 x 180.0 x 140.0

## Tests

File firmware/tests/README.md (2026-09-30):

# Pruebas independientes de hardware

Cada carpeta contiene un sketch Arduino independiente. Conecte un elemento bajo prueba a la vez, verifique alimentacion/GND comun y confirme el pin en ../../hardware/pin_map.md antes de cargarlo.

| Carpeta | Elemento |
| --- | --- |
| aro_led | Aro NeoPixel |
| blink_led | LED basico |
| bombas | Bombas de agua |
| bombas_aro_led | Prueba combinada de bombas y aro LED |
| garra_v1, garra_v2 | Servo de pinza |
| sensor_magnetico | Sensor magnetico |
| sensor_presion | Sensor de presion |

El diagnostico independiente del mando Bluetooth es un programa Python, no un sketch: interface/prueba_control_mando.py.

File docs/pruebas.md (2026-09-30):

# Procedimiento de pruebas

1. Inspeccion mecanica y electrica: revisar conectores, polaridad, aislamiento, sujecion del sensor y estanqueidad antes de instalar electronica sensible.
2. Prueba de sensores sin actuadores: cargar el firmware integrado, iniciar a 115200 baudios y confirmar la deteccion del MS5837 y el BNO055/SEN0374 en el monitor. Cerrar el monitor antes de ejecutar Python.
3. Orientacion: comprobar las tres rotaciones del vehiculo y la telemetria. Giro alrededor del eje longitudinal debe cambiar roll; morro arriba/abajo debe cambiar pitch; giro horizontal alrededor del eje vertical debe cambiar yaw/heading. Confirmar que el rumbo deja de aparecer como -- y revisar la calibracion del magnetometro.
4. Mando: ejecutar interface/prueba_control_mando.py para verificar indices de ejes y botones sin accionar el ROV.
5. Actuadores en banco: mantener el ROV asegurado, comprobar ESC en neutro (1500 us), y probar bombas, aire, electrovalvula y pinza individualmente. Usar stop si algo responde distinto a lo esperado.
6. Interfaz integrada: configurar COM y camara en interface/solo_control.py; verificar telemetria, HUD, mandos, estado LISTO/OPERANDO y reinicio seguro.
7. Captura: iniciar/detener video con boton 10 y confirmar que el contador aparezca en HUD. Revisar el CSV de la sesion y su copia en Logs_Submarino/Respaldo.
8. Prueba en agua: empezar con el vehiculo asegurado y una inmersion progresiva. Demostrar movimiento teleoperado en X/Y/Z/yaw, estabilidad razonable de roll/pitch, video y pinza. Registrar profundidad, condiciones, bateria, comandos y anomalias.

Los angulos se monitorizan y registran; este firmware no aplica estabilizacion automatica de pitch/roll ni control automatico de profundidad. Para cada prueba registre fecha, version de firmware, hardware, resultado y fallas.

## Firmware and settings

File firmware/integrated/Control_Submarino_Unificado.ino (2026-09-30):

/*
  Control unificado para ESP32-S3
  Control por Monitor Serial a 115200 baudios, fin de linea: Nueva linea.

  Librerias necesarias:
  - ESP32Servo
  - Adafruit NeoPixel
  - MS5837 (Blue Robotics / Rob Tillaart compatible con MS5837.h)
  - DFRobot_BNO055 (biblioteca oficial para SEN0374; se instala desde el ZIP de GitHub)
*/

#include <Wire.h>
#include <math.h>
#include <ESP32Servo.h>
#include <Adafruit_NeoPixel.h>
#include <Preferences.h>
#include "MS5837.h"
#include "DFRobot_BNO055.h"

typedef DFRobot_BNO055_IIC BNO055;
BNO055 bno055_28(&Wire, 0x28);
BNO055 bno055_29(&Wire, 0x29);
BNO055 *sensorBno055 = nullptr;

// ------------------------- Pines asignados -------------------------
constexpr uint8_t PIN_ACS712 = 1;
constexpr uint8_t PIN_BATERIA = 10;
constexpr uint8_t PIN_I2C_SDA = 8;
constexpr uint8_t PIN_I2C_SCL = 9;
constexpr uint8_t BNO055_DIRECCION_1 = 0x28;
constexpr uint8_t BNO055_DIRECCION_2 = 0x29;
constexpr uint8_t PIN_SERVO_PINZA = 2;
constexpr uint8_t PIN_ESC = 15;
constexpr uint8_t PIN_BOMBA_AI = 4;
constexpr uint8_t PIN_BOMBA_AD = 5;
constexpr uint8_t PIN_BOMBA_BI = 11;
constexpr uint8_t PIN_BOMBA_BD = 12;
constexpr uint8_t PIN_AIRE_1 = 6;
constexpr uint8_t PIN_AIRE_2 = 7;
constexpr uint8_t PIN_ELECTROVALVULA = 13;
constexpr uint8_t PIN_NEOPIXEL = 21;
constexpr uint8_t NUM_PIXELS = 16;  // Cambie este valor si su aro tiene otra cantidad.

// true si el GPIO15 maneja la entrada del ESC mediante NPN de emisor comun.
// El PWM de hardware se invierte para compensar la inversion del transistor.
constexpr bool ESC_USA_TRANSISTOR_NPN = true;
constexpr bool ESC_REVERSIBLE = true;
constexpr unsigned long TIEMPO_ARMADO_ESC_MS = 3000;
// Telemetria a 10 Hz: deja margen para las conversiones de 20 ms del MS5837.
constexpr unsigned long INTERVALO_TELEMETRIA_MS = 100;
constexpr int ESC_PULSO_MINIMO = 1000;
constexpr int ESC_PULSO_NEUTRO = ESC_REVERSIBLE ? 1500 : 1000;
constexpr int ESC_PULSO_MAXIMO = 2000;
constexpr uint32_t PERIODO_ESC_US = 20000;
constexpr uint8_t ESC_PWM_RESOLUCION = 14;
constexpr uint32_t ESC_PWM_DUTY_MAX = (1UL << ESC_PWM_RESOLUCION) - 1;

// Divisor de bateria: 30 kOhm arriba y 10 kOhm abajo.
constexpr float FACTOR_DIVISOR_BATERIA_PREDETERMINADO = 4.2318f;
constexpr float VOLTAJE_BATERIA_BAJO_V = 10.5f;
constexpr unsigned long TIEMPO_CONFIGURACION_LED_MS = 5000;
// ACS712 (20A) alimentado a 5V con divisor 10k/10k a la salida
constexpr float FACTOR_DIVISOR_ACS712 = 2.0f;      // Divisor 10k/10k (divide por 2)
constexpr float ACS712_SENSIBILIDAD_V_A = 0.100f; // 100 mV/A para el modelo ACS712-20B
constexpr float ACS712_ZONA_CERO_A = 0.08f;
constexpr uint16_t MUESTRAS_ADC = 128;
constexpr float DENSIDAD_AGUA_KG_M3 = 997.0f;
constexpr float GRAVEDAD_M_S2 = 9.80665f;
const uint8_t MODELO_MS5837 = MS5837::MS5837_02BA;

Servo servoPinza;
Adafruit_NeoPixel pixels(NUM_PIXELS, PIN_NEOPIXEL, NEO_GRB + NEO_KHZ800);
MS5837 presion;
Preferences preferencias;

bool imuDisponible = false;
bool magnetometroDisponible = false;
bool lecturaImuValida = false;
bool lecturaMagValida = false;
bool presionDisponible = false;
bool escPwmDisponible = false;
bool sistemaOperando = false;
bool lecturaAcsValida = false;
bool lecturaBateriaValida = false;
bool lecturaPresionValida = false;
float voltajeBateriaActual = 0.0f;
uint8_t fallosLecturaImu = 0;
uint8_t fallosLecturaMag = 0;
uint8_t direccionBno055 = 0;
uint8_t calibracionSistema = 0;
uint8_t calibracionGiroscopio = 0;
uint8_t calibracionAcelerometro = 0;
uint8_t calibracionMagnetometro = 0;
float ceroAcsPinV = 1.25f;
float factorDivisorBateria = FACTOR_DIVISOR_BATERIA_PREDETERMINADO;
float presionSuperficieMbar = 1013.25f;
bool superficieCalibrada = false;
float aceleracionX = 0, aceleracionY = 0, aceleracionZ = 0;
float giroX = 0, giroY = 0, giroZ = 0;
float magnetometroX = 0, magnetometroY = 0, magnetometroZ = 0;
float rollImu = 0, pitchImu = 0, rumboImu = 0;
unsigned long ultimaLecturaImuMs = 0;
unsigned long ultimaSalidaSensoresMs = 0;
unsigned long ultimoCeroAcsMs = 0;
unsigned long escNeutroDesdeMs = 0;
float corrienteFiltradaA = 0;
bool filtroCorrienteInicializado = false;
uint8_t filasTabla = 0;
int servoAngulo = 110;
int escMicrosegundos = ESC_PULSO_NEUTRO;

enum ModoLed { LED_APAGADO, LED_ERROR, LED_CONFIG, LED_LISTO, LED_OPERANDO, LED_BATERIA };
ModoLed modoLed = LED_APAGADO;
unsigned long inicioSistemaMs = 0;
unsigned long ultimoLedMs = 0;
uint16_t pixelConfiguracion = 0;
int brilloOperacion = 5;
int pasoBrillo = 1;
bool estadoParpadeo = false;

void apagarBombasAgua();
void apagarAire();
void apagarTodo();
void procesarComando(char *comando);
void actualizarLeds();
bool hayFallaSensores();
void colorTodos(uint8_t r, uint8_t g, uint8_t b);
void leerSensores();
void imprimirAyuda();
float leerVoltajeAdcPromedio(uint8_t pin);
void calibrarCorriente();
void calibrarSuperficie();
void imprimirCalibracionBNO055(const char *mensaje);
void actualizarBNO055();
void actualizarCeroCorrienteAutomatico();
void imprimirEncabezadoTabla();
void escanearI2C();
bool hayDispositivoI2C(uint8_t direccion);
void iniciarBNO055();
bool actualizarEsc();

void setup() {
  Serial.begin(115200);
  Serial.setTimeout(50);
  inicioSistemaMs = millis();

  pixels.begin();
  pixels.setBrightness(40);
  colorTodos(255, 120, 0);  // Configuracion visible desde el encendido.

  pinMode(PIN_BOMBA_AI, OUTPUT);
  pinMode(PIN_BOMBA_AD, OUTPUT);
  pinMode(PIN_BOMBA_BI, OUTPUT);
  pinMode(PIN_BOMBA_BD, OUTPUT);
  pinMode(PIN_AIRE_1, OUTPUT);
  pinMode(PIN_AIRE_2, OUTPUT);
  pinMode(PIN_ELECTROVALVULA, OUTPUT);
  analogReadResolution(12);
  analogSetPinAttenuation(PIN_ACS712, ADC_11db);
  analogSetPinAttenuation(PIN_BATERIA, ADC_11db);
  preferencias.begin("submarino", false);
  factorDivisorBateria = preferencias.getFloat("factor_bat", FACTOR_DIVISOR_BATERIA_PREDETERMINADO);
  apagarTodo();

  servoPinza.setPeriodHertz(50);
  servoPinza.attach(PIN_SERVO_PINZA, 500, 2400);
  servoPinza.write(servoAngulo);

  pinMode(PIN_ESC, OUTPUT);
  digitalWrite(PIN_ESC, ESC_USA_TRANSISTOR_NPN ? HIGH : LOW);
  escPwmDisponible = ledcAttach(PIN_ESC, 50, ESC_PWM_RESOLUCION);
  if (!escPwmDisponible) {
    Serial.println("ERROR: no se pudo configurar PWM LEDC para el ESC.");
  } else if (!actualizarEsc()) {
    Serial.println("ERROR: LEDC no pudo escribir el pulso inicial del ESC.");
    escPwmDisponible = false;
  } else {
    Serial.printf("PWM ESC: LEDC 50 Hz, pulso %d us, reversible=%s, NPN=%s.\n", escMicrosegundos, ESC_REVERSIBLE ? "si" : "no", ESC_USA_TRANSISTOR_NPN ? "si" : "no");
  }

  Wire.begin(PIN_I2C_SDA, PIN_I2C_SCL);
  Wire.setClock(100000);
  escanearI2C();
  iniciarBNO055();

  presionDisponible = presion.init();
  if (presionDisponible) {
    presion.setModel(MODELO_MS5837);
    calibrarSuperficie();
  }
  Serial.println("\nControl submarino ESP32-S3 listo.");
  if (imuDisponible) Serial.printf("BNO055/SEN0374: OK en I2C 0x%02X | Magnetometro integrado: OK\n", direccionBno055);
  else Serial.println("BNO055/SEN0374: NO detectado en 0x28/0x29 | Magnetometro integrado: NO disponible.");
  Serial.printf("MS5837: %s\n", presionDisponible ? "OK" : "NO detectado");
  Serial.printf("ESC: espere %lu ms en neutro para el armado.\n", TIEMPO_ARMADO_ESC_MS);
  delay(TIEMPO_ARMADO_ESC_MS);
  calibrarCorriente();  // Cero automático al arrancar con ESC en neutro.
  escNeutroDesdeMs = millis();
  imprimirAyuda();
  imprimirEncabezadoTabla();
  Serial.println("CONTROL_LISTO");
}

void loop() {
  static char linea[64];
  static uint8_t longitud = 0;

  while (Serial.available()) {
    char c = static_cast<char>(Serial.read());
    if (c == '\r') continue;
    if (c == '\n') {
      linea[longitud] = '\0';
      if (longitud > 0) procesarComando(linea);
      longitud = 0;
    } else if (longitud < sizeof(linea) - 1) {
      linea[longitud++] = c;
    }
  }
  actualizarBNO055();
  actualizarCeroCorrienteAutomatico();
  if (millis() - ultimaSalidaSensoresMs >= INTERVALO_TELEMETRIA_MS) {
    ultimaSalidaSensoresMs = millis();
    leerSensores();
  }
  actualizarLeds();
}

void procesarComando(char *comando) {
  for (char *p = comando; *p; ++p) *p = tolower(*p);

  if (!strcmp(comando, "conectar") || !strcmp(comando, "ping")) Serial.println("CONTROL_LISTO");
  else if (!strcmp(comando, "ayuda") || !strcmp(comando, "help")) imprimirAyuda();
  else if (!strcmp(comando, "estado") || !strcmp(comando, "sensores")) leerSensores();
  else if (!strcmp(comando, "reiniciar") || !strcmp(comando, "reinicio") || !strcmp(comando, "reset")) {
    sistemaOperando = false;
    apagarTodo();
    escMicrosegundos = ESC_PULSO_NEUTRO;
    actualizarEsc();
    escNeutroDesdeMs = millis();
    Serial.println("Reinicio solicitado: actuadores apagados y ESC en neutro.");
    Serial.flush();
    delay(250);
    ESP.restart();
  }
  else if (!strcmp(comando, "calibrar_superficie")) calibrarSuperficie();
  else if (!strcmp(comando, "calibrar_imu")) { if (imuDisponible) imprimirCalibracionBNO055("Calibracion BNO055 (0=sin calibrar, 3=calibrado):"); else Serial.println("BNO055 no disponible."); }
  else if (!strcmp(comando, "calibrar_brujula")) {
    if (magnetometroDisponible) {
      Serial.println("Mueva el submarino lentamente en varias orientaciones, dibujando ochos, lejos de metales y corrientes del motor.");
      imprimirCalibracionBNO055("Estado de calibracion BNO055 (0=sin calibrar, 3=calibrado):");
    } else Serial.println("BNO055/magnetometro integrado no disponible.");
  }
  else if (!strncmp(comando, "calibrar_bateria ", 17)) {
    float referencia = atof(comando + 17);
    float voltajePin = leerVoltajeAdcPromedio(PIN_BATERIA);
    if (referencia >= 5.0f && referencia <= 25.0f && voltajePin > 0.1f) {
      factorDivisorBateria = referencia / voltajePin;
      preferencias.putFloat("factor_bat", factorDivisorBateria);
      Serial.printf("Bateria calibrada: referencia %.3f V, ADC %.3f V, factor %.5f (guardado).\n", referencia, voltajePin, factorDivisorBateria);
    } else Serial.println("Uso: calibrar_bateria <voltaje medido con multimetro, 5..25 V>.");
  }
  else if (!strcmp(comando, "iniciar")) {
    sistemaOperando = true;
    Serial.println("Control en modo OPERANDO.");
  }
  else if (!strcmp(comando, "stop") || !strcmp(comando, "parar")) {
    sistemaOperando = false;
    apagarTodo();
    escMicrosegundos = ESC_PULSO_NEUTRO;
    actualizarEsc();
    escNeutroDesdeMs = millis();
    Serial.println("Todo detenido; ESC en neutro.");
  }
  // Bombas de agua: la combinacion se conserva de los sketches originales.
  else if (!strcmp(comando, "adelante") || !strcmp(comando, "a")) {
    apagarBombasAgua(); digitalWrite(PIN_BOMBA_AI, HIGH); digitalWrite(PIN_BOMBA_AD, HIGH); Serial.println("Bombas de agua: adelante.");
  } else if (!strcmp(comando, "derecha") || !strcmp(comando, "d")) {
    apagarBombasAgua(); digitalWrite(PIN_BOMBA_AI, HIGH); digitalWrite(PIN_BOMBA_BI, HIGH); Serial.println("Bombas de agua: giro derecha.");
  } else if (!strcmp(comando, "izquierda") || !strcmp(comando, "i")) {
    apagarBombasAgua(); digitalWrite(PIN_BOMBA_AD, HIGH); digitalWrite(PIN_BOMBA_BD, HIGH); Serial.println("Bombas de agua: giro izquierda.");
  } else if (!strcmp(comando, "roll_derecha") || !strcmp(comando, "rd")) {
    apagarBombasAgua(); digitalWrite(PIN_BOMBA_AD, HIGH); digitalWrite(PIN_BOMBA_BI, HIGH); Serial.println("Bombas de agua: roll derecha.");
  } else if (!strcmp(comando, "roll_izquierda") || !strcmp(comando, "ri")) {
    apagarBombasAgua(); digitalWrite(PIN_BOMBA_AI, HIGH); digitalWrite(PIN_BOMBA_BD, HIGH); Serial.println("Bombas de agua: roll izquierda.");
  } else if (!strcmp(comando, "agua_off")) {
    apagarBombasAgua(); Serial.println("Bombas de agua apagadas.");
  }
  else if (!strcmp(comando, "aire1_on")) { digitalWrite(PIN_AIRE_1, HIGH); Serial.println("Bomba de aire 1 encendida."); }
  else if (!strcmp(comando, "aire1_off")) { digitalWrite(PIN_AIRE_1, LOW); Serial.println("Bomba de aire 1 apagada."); }
  else if (!strcmp(comando, "aire2_on")) { digitalWrite(PIN_AIRE_2, HIGH); Serial.println("Bomba de aire 2 encendida."); }
  else if (!strcmp(comando, "aire2_off")) { digitalWrite(PIN_AIRE_2, LOW); Serial.println("Bomba de aire 2 apagada."); }
  else if (!strcmp(comando, "aire_on")) { digitalWrite(PIN_AIRE_1, HIGH); digitalWrite(PIN_AIRE_2, HIGH); Serial.println("Bombas de aire encendidas."); }
  else if (!strcmp(comando, "aire_off")) { apagarAire(); Serial.println("Bombas de aire apagadas."); }
  else if (!strcmp(comando, "valvula_on")) { digitalWrite(PIN_ELECTROVALVULA, HIGH); Serial.println("Electrovalvula encendida."); }
  else if (!strcmp(comando, "valvula_off")) { digitalWrite(PIN_ELECTROVALVULA, LOW); Serial.println("Electrovalvula apagada."); }
  else if (!strncmp(comando, "servo ", 6)) {
    int angulo = atoi(comando + 6);
    if (angulo >= 0 && angulo <= 180) { servoAngulo = angulo; servoPinza.write(servoAngulo); Serial.printf("Pinza: %d grados.\n", servoAngulo); }
    else Serial.println("Angulo invalido: use servo 0..180.");
  } else if (!strcmp(comando, "abrir")) { servoAngulo = 165; servoPinza.write(servoAngulo); Serial.println("Pinza abierta."); }
  else if (!strcmp(comando, "cerrar")) { servoAngulo = 110; servoPinza.write(servoAngulo); Serial.println("Pinza cerrada."); }
  else if (!strncmp(comando, "esc ", 4)) {
    int pulso = atoi(comando + 4);
    if (pulso >= ESC_PULSO_MINIMO && pulso <= ESC_PULSO_MAXIMO) {
      escMicrosegundos = pulso;
      if (!actualizarEsc()) { Serial.println("ERROR: no se pudo actualizar el PWM del ESC."); return; }
      escNeutroDesdeMs = escMicrosegundos == ESC_PULSO_NEUTRO ? millis() : 0;
    }
    else Serial.println("Pulso invalido: use esc 1000..2000.");
  } else if (!strcmp(comando, "esc_off")) { escMicrosegundos = ESC_PULSO_NEUTRO; actualizarEsc(); escNeutroDesdeMs = millis(); }
  else Serial.println("Comando no valido. Escriba ayuda.");
}

void apagarBombasAgua() { digitalWrite(PIN_BOMBA_AI, LOW); digitalWrite(PIN_BOMBA_AD, LOW); digitalWrite(PIN_BOMBA_BI, LOW); digitalWrite(PIN_BOMBA_BD, LOW); }
void apagarAire() { digitalWrite(PIN_AIRE_1, LOW); digitalWrite(PIN_AIRE_2, LOW); }
void apagarTodo() { apagarBombasAgua(); apagarAire(); digitalWrite(PIN_ELECTROVALVULA, LOW); }

bool actualizarEsc() {
  if (!escPwmDisponible) return false;
  uint32_t tiempoAltoPinUs = ESC_USA_TRANSISTOR_NPN
      ? PERIODO_ESC_US - static_cast<uint32_t>(escMicrosegundos)
      : static_cast<uint32_t>(escMicrosegundos);
  uint32_t duty = (tiempoAltoPinUs * ESC_PWM_DUTY_MAX + PERIODO_ESC_US / 2)
      / PERIODO_ESC_US;
  return ledcWrite(PIN_ESC, duty);
}

float leerVoltajeAdcPromedio(uint8_t pin) {
  uint32_t suma = 0;
  for (uint16_t i = 0; i < MUESTRAS_ADC; ++i) suma += analogReadMilliVolts(pin);
  return (suma / static_cast<float>(MUESTRAS_ADC)) / 1000.0f;
}

void calibrarCorriente() {
  delay(20);
  ceroAcsPinV = leerVoltajeAdcPromedio(PIN_ACS712);
  corrienteFiltradaA = 0;
  filtroCorrienteInicializado = false;
  Serial.printf("ACS712 auto-cero: %.3f V con ESC en neutro.\n", ceroAcsPinV);
}

void calibrarSuperficie() {
  if (!presionDisponible) { Serial.println("MS5837 no disponible."); return; }
  presion.read();
  presionSuperficieMbar = presion.pressure();
  superficieCalibrada = true;
  Serial.printf("Superficie calibrada: %.2f mbar.\n", presionSuperficieMbar);
}

bool hayDispositivoI2C(uint8_t direccion) {
  Wire.beginTransmission(direccion);
  return Wire.endTransmission() == 0;
}

void escanearI2C() {
  Serial.printf("I2C: SDA GPIO %u, SCL GPIO %u. Direcciones detectadas:", PIN_I2C_SDA, PIN_I2C_SCL);
  bool encontrado = false;
  for (uint8_t direccion = 1; direccion < 127; ++direccion) {
    if (hayDispositivoI2C(direccion)) { Serial.printf(" 0x%02X", direccion); encontrado = true; }
  }
  if (!encontrado) Serial.print(" ninguna");
  Serial.println();
}

void iniciarBNO055() {
  const uint8_t direcciones[] = {BNO055_DIRECCION_1, BNO055_DIRECCION_2};
  BNO055 *candidatos[] = {&bno055_28, &bno055_29};
  for (uint8_t i = 0; i < 2; ++i) {
    uint8_t direccion = direcciones[i];
    if (!hayDispositivoI2C(direccion)) continue;
    Serial.printf("Probando biblioteca DFRobot_BNO055 en 0x%02X... ", direccion);
    BNO055::eStatus_t estado = candidatos[i]->begin();
    if (estado != BNO055::eStatusOK) {
      Serial.printf("inicio fallido (estado %d).\n", static_cast<int>(estado));
      continue;
    }

    sensorBno055 = candidatos[i];
    direccionBno055 = direccion;
    // begin() de DFRobot ya inicia el NDOF; se fija otra vez para dejar claro
    // que necesitamos orientacion fusionada con acelerometro, gyro y magnetometro.
    sensorBno055->setOprMode(BNO055::eOprModeNdof);
    imuDisponible = true;
    magnetometroDisponible = true; // El magnetometro va integrado en el BNO055.
    Serial.printf("BNO055 listo en 0x%02X, modo NDOF por biblioteca DFRobot.\n", direccionBno055);
    actualizarBNO055();
    imprimirCalibracionBNO055("Calibracion inicial BNO055 (0=sin calibrar, 3=calibrado):");
    return;
  }
  Serial.println("No se pudo iniciar la biblioteca DFRobot_BNO055 en 0x28 ni 0x29.");
}

void actualizarBNO055() {
  if (!imuDisponible || sensorBno055 == nullptr || millis() - ultimaLecturaImuMs < 10) return;
  ultimaLecturaImuMs = millis();

  // DFRobot entrega accel en mg, magnetometro en uT, gyro en dps y Euler en grados.
  BNO055::sAxisAnalog_t accel = sensorBno055->getAxis(BNO055::eAxisAcc);
  BNO055::sAxisAnalog_t mag = sensorBno055->getAxis(BNO055::eAxisMag);
  BNO055::sAxisAnalog_t gyro = sensorBno055->getAxis(BNO055::eAxisGyr);
  BNO055::sEulAnalog_t euler = sensorBno055->getEul();
  if (sensorBno055->lastOperateStatus != BNO055::eStatusOK) {
    lecturaImuValida = false;
    lecturaMagValida = false;
    if (fallosLecturaImu < 5) ++fallosLecturaImu;
    if (fallosLecturaMag < 5) ++fallosLecturaMag;
    return;
  }

  aceleracionX = accel.x / 1000.0f;
  aceleracionY = accel.y / 1000.0f;
  aceleracionZ = accel.z / 1000.0f;
  magnetometroX = mag.x;
  magnetometroY = mag.y;
  magnetometroZ = mag.z;
  giroX = gyro.x;
  giroY = gyro.y;
  giroZ = gyro.z;
  rumboImu = euler.head;
  rollImu = euler.roll;
  pitchImu = euler.pitch;
  while (rumboImu < 0.0f) rumboImu += 360.0f;
  while (rumboImu >= 360.0f) rumboImu -= 360.0f;

  lecturaImuValida = isfinite(aceleracionX) && isfinite(aceleracionY) && isfinite(aceleracionZ) &&
                     isfinite(giroX) && isfinite(giroY) && isfinite(giroZ) && isfinite(rollImu) && isfinite(pitchImu);
  lecturaMagValida = isfinite(magnetometroX) && isfinite(magnetometroY) && isfinite(magnetometroZ) && isfinite(rumboImu);
  if (lecturaImuValida) fallosLecturaImu = 0;
  if (lecturaMagValida) fallosLecturaMag = 0;

  BNO055::sRegCalibState_t calibracion = sensorBno055->getCalStatus();
  if (sensorBno055->lastOperateStatus == BNO055::eStatusOK) {
    calibracionSistema = calibracion.SYS;
    calibracionGiroscopio = calibracion.GYR;
    calibracionAcelerometro = calibracion.ACC;
    calibracionMagnetometro = calibracion.MAG;
  }
}

void imprimirCalibracionBNO055(const char *mensaje) {
  if (!imuDisponible || sensorBno055 == nullptr) { Serial.println("BNO055 no disponible."); return; }
  BNO055::sRegCalibState_t calibracion = sensorBno055->getCalStatus();
  if (sensorBno055->lastOperateStatus != BNO055::eStatusOK) {
    Serial.println("No se pudo leer el estado de calibracion del BNO055.");
    return;
  }
  calibracionSistema = calibracion.SYS;
  calibracionGiroscopio = calibracion.GYR;
  calibracionAcelerometro = calibracion.ACC;
  calibracionMagnetometro = calibracion.MAG;
  Serial.printf("%s Sistema=%u, gyro=%u, accel=%u, magnetometro=%u.\n",
                mensaje, calibracionSistema, calibracionGiroscopio,
                calibracionAcelerometro, calibracionMagnetometro);
}
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

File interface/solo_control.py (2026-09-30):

"""Controla el submarino con el mando PG-9076 y el ESP32 por puerto serie."""

import os
import sys
import time
import math
import ctypes
import csv
import shutil
from collections import deque
from datetime import datetime

# El programa usa una ventana oculta; permite que SDL actualice el mando sin foco.
os.environ["SDL_JOYSTICK_ALLOW_BACKGROUND_EVENTS"] = "1"

import pygame
import serial

# La interfaz usa OpenCV como en "vsc interfaz.txt". Si falta alguna dependencia,
# el control del submarino sigue funcionando por consola.
try:
    import cv2
    import numpy as np
except ImportError as error:
    cv2 = None
    np = None
    print(f"Interfaz visual no disponible ({error}); el control seguira por consola.")


# Cambiar COM3 si Windows asigna otro puerto al ESP32.
PUERTO_COM = "COM3"
BAUDIOS = 115200
DEADZONE = 0.25
REENVIO_MOVIMIENTO_S = 0.15
ESPERA_ESP32_S = 30
TIEMPO_SIN_TELEMETRIA_S = 10.0
TIEMPO_SUAVIZADO_ACTITUD_S = 0.45

# Telemetria tabular enviada por Control_Submarino_Unificado.ino, en el orden
# de sus 24 columnas, incluidas las cuatro calibraciones internas del BNO055.
# El mismo puerto serie se comparte con los comandos.
CAMPOS_TELEMETRIA = (
    "acs_v", "corriente_a", "potencia_w", "bateria_v", "esc_us",
    "presion_mbar", "temperatura_c", "profundidad_m",
    "ax_g", "ay_g", "az_g", "gx_dps", "gy_dps", "gz_dps",
    "mx_ut", "my_ut", "mz_ut", "roll_deg", "pitch_deg", "yaw_deg",
    "cal_sistema", "cal_giroscopio", "cal_acelerometro", "cal_magnetometro",
)
COLUMNAS_LOG = (
    "acs712_adc_v", "corriente_motor_a", "potencia_motor_w", "bateria_v", "esc_us",
    "presion_mbar", "temperatura_c", "profundidad_m", "aceleracion_x_g", "aceleracion_y_g",
    "aceleracion_z_g", "giroscopio_x_dps", "giroscopio_y_dps", "giroscopio_z_dps",
    "magnetometro_x_ut", "magnetometro_y_ut", "magnetometro_z_ut", "roll_deg", "pitch_deg", "yaw_deg",
    "bno055_calibracion_sistema_0_3", "bno055_calibracion_giroscopio_0_3",
    "bno055_calibracion_acelerometro_0_3", "bno055_calibracion_magnetometro_0_3",
)
telemetria = {campo: None for campo in CAMPOS_TELEMETRIA}
ultima_telemetria = 0.0
fallo_reportado_esp32 = False
historial_telemetria = deque(maxlen=600)  # Ultimos 60 s a 10 Hz.
escritores_log = []
salidas_log_pendientes = []
inicio_logs_monotonic = None
logs_activos = False
respaldo_log_activo = False
ruta_log_respaldo = None
ultimo_intento_reparacion_log = 0.0
GRUPOS_SENSORES = {
    "ACS712": ("acs_v",),
    "BATERIA": ("bateria_v",),
    "MS5837": ("presion_mbar", "temperatura_c", "profundidad_m"),
    "BNO055": (
        "ax_g", "ay_g", "az_g", "gx_dps", "gy_dps", "gz_dps",
        "mx_ut", "my_ut", "mz_ut", "roll_deg", "pitch_deg", "yaw_deg",
    ),
}
roll_hud_filtrado = 0.0
pitch_hud_filtrado = 0.0
ultimo_filtro_actitud = 0.0

# Opciones visuales heredadas del HUD de "vsc interfaz.txt".
CAMARA = 1  # La camara principal suele ser 0; la webcam USB secundaria, 1.
VAL_CONTRASTE = 1.24
VAL_SATURACION = 1.70
CARPETA_VIDEOS = "Grabaciones_HUD"
CARPETA_LOGS = os.path.join(os.path.dirname(os.path.abspath(__file__)), "Logs_Submarino")
NOMBRE_VENTANA = "Sistema de Vision Submarino"
try:
    ANCHO_PANTALLA = ctypes.windll.user32.GetSystemMetrics(0)
    ALTO_PANTALLA = ctypes.windll.user32.GetSystemMetrics(1)
except (AttributeError, OSError):
    ANCHO_PANTALLA, ALTO_PANTALLA = 1280, 720

captura = None
grabando = False
video_writer = None
inicio_grabacion = None
INTERFAZ_ACTIVA = cv2 is not None
vista_graficas = False

# Mapeo medido en prueba control.py; Pygame entrega algunos ejes duplicados.
EJE_IZQUIERDO_Y = 1
# EJE[2] duplica al motor; EJE[5] duplica el vertical derecho.
EJE_DERECHO_X = 3
EJE_DERECHO_Y = 4

# Indices confirmados en la prueba de Windows/Pygame.
BOTON_A, BOTON_B, BOTON_X, BOTON_Y = 0, 1, 3, 4
BOTON_START = 11
BOTON_GRABAR = 10
BOTON_REINICIAR_ESP32 = BOTON_A
BOTON_VALVULA = 7

# Debe coincidir con ESC_REVERSIBLE en el sketch Arduino.
ESC_REVERSIBLE = True
PULSO_ESC_NEUTRO = 1500 if ESC_REVERSIBLE else 1000


def limitar(valor, minimo, maximo):
    return max(minimo, min(maximo, valor))


def actualizar_telemetria(linea):
    """Acepta filas actuales (24 datos) y antiguas (20 datos, sin cal BNO055)."""
    global ultima_telemetria, fallo_reportado_esp32
    texto = linea.strip()
    if "ERROR:" in texto.upper():
        fallo_reportado_esp32 = True
    if texto.startswith("ESP32:"):
        texto = texto[len("ESP32:"):].strip()
    columnas = texto.split()
    # El firmware previo enviaba 20 columnas; el que integra BNO055 agrega
    # cuatro estados de calibracion. Rechaza encabezados y mensajes parciales.
    if len(columnas) not in (20, len(CAMPOS_TELEMETRIA)):
        return False
    # Los campos nuevos quedan vacios al recibir una fila del firmware antiguo.
    nuevos = {campo: None for campo in CAMPOS_TELEMETRIA}
    try:
        for nombre, token in zip(CAMPOS_TELEMETRIA, columnas[:len(CAMPOS_TELEMETRIA)]):
            nuevos[nombre] = None if token == "--" else float(token.replace(",", "."))
    except ValueError:
        return False
    telemetria.update(nuevos)
    ahora = time.monotonic()
    ultima_telemetria = ahora
    historial_telemetria.append((ahora, nuevos.copy()))
    registrar_fila_log(nuevos, ahora)
    return True
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

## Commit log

2026-09-16 chore: estructura inicial del ROV
    [BOM_Tesis_2026-08-29.csv, telemetria_ejemplo.csv]
2026-09-23 Update firmware and add project evidence
    [Pieza_frontal.stl, Pieza_trasera.stl]
2026-09-30 Update ROV firmware, interface, and evidence
    [soporte_1.stl, soporte_2.stl, soporte_3.stl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]
2026-10-22 Update submarine control and toroidal propeller
